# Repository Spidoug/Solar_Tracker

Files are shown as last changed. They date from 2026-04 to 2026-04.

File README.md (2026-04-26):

# Solar Tracker

videoframe_57683

**Solar Tracker** is an Arduino-based photovoltaic panel positioning system. It uses two LDR sensors, an irradiance input, a servo motor, a compass module, an RTC module, EEPROM persistence, and a browser-based Web Serial control interface to keep a solar panel aligned with the most favorable light direction during the configured operating window.

The project combines embedded control and a lightweight web dashboard. The Arduino firmware performs the real-time tracking logic, while the HTML interface allows the operator to connect through USB serial, set angles, sync the RTC, configure sunrise and sunset times, adjust magnetic declination, toggle operation modes, record calibration data, and export CSV files.



## Project objective

The objective of this project is to maximize solar energy capture by orienting a photovoltaic panel toward the best available solar incidence angle throughout the day. The system is designed for small photovoltaic installations, educational experiments, solar-energy research, and prototypes that need low-cost automatic solar tracking.

The tracker uses LDR readings to compare light intensity on the east and west sides of the panel, an analog irradiance input to estimate solar incidence, an HMC5883L compass module to support orientation checks, and an RTC module to keep operation limited to a configured sunrise-to-sunset period. Configuration values are stored in EEPROM, allowing the system to keep important parameters after power cycling.

## Main features

- Arduino firmware for UNO, NANO, MEGA, and compatible boards.
- Servo-based panel angle control from **30° to 150°**.
- Active solar tracking based on LDR difference and PID control.
- Passive solar tracking based on time progression between sunrise and sunset.
- Manual positioning mode through the serial menu or web interface.
- Auto-calibration routine for finding the angle with maximum irradiance.
- RTC-based operating schedule.
- HMC5883L compass orientation check with magnetic declination compensation.
- EEPROM persistence for operating mode, schedule, magnetic declination, and filter state.
- Sudden-variation filter for reducing unstable movement caused by temporary shadows or fast irradiance disturbances.
- Buzzer alerts for startup, movement, confirmation, orientation errors, RTC errors, compass errors, and invalid input.
- Browser-based control panel using the Web Serial API.
- Real-time chart for irradiance versus panel angle using Chart.js.
- CSV export for calibration or experiment data.
- Included STL files for 3D-printed mechanical parts.

## Repository structure

```text
Solar-Tracker/
├── README.md
├── CHANGELOG.md
├── CONTRIBUTING.md
├── LICENSE
├── NOTICE.md
├── SECURITY.md
├── docs/
│   ├── ARDUINO_FIRMWARE.md
│   ├── HARDWARE_GUIDE.md
│   ├── OPERATING_GUIDE.md
│   ├── SERIAL_PROTOCOL.md
│   ├── WEB_APP.md
│   ├── TROUBLESHOOTING.md
│   └── ORIGINAL_README.md
├── hardware/
│   └── 3d-models/
│       ├── FanStBase.stl
│       ├── FanStGrille.stl
│       ├── FanStVert.stl
│       ├── Laser_Cradle_9mm_SG90.stl
│       ├── Servo_Box_3.stl
│       ├── arduino_uno_bottom.stl
│       └── arduino_uno_top.stl
└── src/
    ├── arduino/
    │   └── Solar_Tracker/
    │       └── Solar_Tracker.ino
    └── web/
        ├── index.html
        └── Solar Tracker.html
```

## System overview

The firmware runs in a loop and reads the sensors once per second. During the configured operating interval, it chooses the appropriate behavior based on the current mode:

In **active mode**, the tracker compares the west and east LDR readings. The difference between these readings becomes the tracking error. The firmware applies a PID-style correction and moves the servo when the error exceeds the configured tolerance.

In **passive mode**, the tracker does not depend primarily on the LDR difference. Instead, it maps the current time between sunrise and sunset to the servo angle range. At sunrise, the servo approaches the minimum angle. At sunset, it approaches the maximum angle.

In **manual mode**, the operator defines the desired angle. The tracker keeps the servo at that manually configured angle until automatic behavior is restored.

Outside the configured operating time, the firmware returns the servo to a neutral position and detaches the servo to reduce unnecessary power consumption.

## Hardware components

The project is designed around commonly available Arduino modules:

| Component | Purpose |
|---|---|
| Arduino UNO/NANO/MEGA or compatible board | Main controller |
| Servo motor, such as SG90 or compatible | Moves the solar panel structure |
| 2 × LDR sensors | Detect light imbalance between east and west sides |
| Irradiance sensor or analog light sensor | Measures solar irradiance through analog input A2 |
| HMC5883L compass module | Provides magnetic orientation data |
| PCF8563 RTC module | Keeps date and time for operating schedule |
| Buzzer | Provides acoustic alerts |
| 3D-printed parts | Mechanical support, servo mount, Arduino case, and structural parts |
| External servo power supply | Recommended for stable motion under load |

## Default pin mapping

| Arduino pin | Connected device | Notes |
|---|---|---|
| A0 | West LDR | Analog input |
| A1 | East LDR | Analog input |
| A2 | Irradiance sensor | Mapped from 0–5 V to 0–1000 W/m² in firmware |
| D3 | Servo signal | PWM-capable output |
| D13 | Buzzer | Tone alerts |
| SDA/SCL | RTC + compass | I2C bus |

For Arduino UNO and NANO, the I2C pins are normally A4/SDA and A5/SCL. For Arduino MEGA, they are normally pins 20/SDA and 21/SCL. Always connect all grounds together, especially when using an external servo power supply.

## Arduino dependencies

Install these libraries in the Arduino IDE before compiling:

- `RTClib`
- `Servo`
- `Adafruit HMC5883 Unified`
- `Adafruit Unified Sensor`, required by the HMC5883 library
- `Wire`, included with the Arduino core
- `EEPROM`, included with the Arduino core

## Getting started

1. Clone or download this repository.
2. Open `src/arduino/Solar_Tracker/Solar_Tracker.ino` in the Arduino IDE.
3. Install the required libraries from the Arduino Library Manager.
4. Select the correct board and serial port.
5. Upload the firmware to the Arduino.
6. Assemble the LDR sensors, irradiance input, compass, RTC, servo motor, and buzzer according to the pin mapping.
7. Open `src/web/index.html` in a browser that supports the Web Serial API.
8. Connect to the Arduino using the **Connect to Arduino** button.
9. Configure time, sunrise/sunset, magnetic declination, and operation mode.
10. Test the servo movement without a heavy panel before installing the final mechanical load.

## Web control interface

The web app is a single HTML file that communicates with the Arduino through USB serial. It provides modules for serial connection, manual angle setting, automatic mode restoration, RTC synchronization, schedule configuration, magnetic declination, active/passive mode switching, sudden-variation filter control, data recording, CSV export, compass display, and an irradiance-versus-angle chart.

The interface sends the same menu commands expected by the Arduino serial menu. For example, the manual angle command sends option `7`, followed by the desired angle.

## Serial menu commands

The firmware exposes a simple text-based serial menu at **9600 baud**:

| Option | Action | Expected follow-up input |
|---|---|---|
| `1` | Adjust system date and time | `YYYY MM DD HH MM SS` |
| `2` | Adjust sunrise time | `HH MM` |
| `3` | Adjust sunset time | `HH MM` |
| `4` | Toggle sudden variation filter | None |
| `5` | Adjust magnetic declination | Decimal value in degrees |
| `6` | Toggle active/passive operation mode | None |
| `7` | Enter manual positioning mode | Angle from 30 to 150; invalid value returns to automatic mode |

The web app uses these commands internally, so both the browser interface and the Arduino Serial Monitor can control the same firmware.

## Operation modes

### Active mode

Active mode uses the two LDR sensors as the main feedback source. The panel moves when the west/east light difference exceeds the tolerance threshold. A PID-style correction is applied using the configured constants in the firmware:

```cpp
float Kp = 0.5, Ki = 0.1, Kd = 0.05;
```

### Passive mode

Passive mode uses the configured sunrise and sunset times to calculate a time ratio. The firmware maps the current time to the servo range from 30° to 150°. This mode is useful when LDR readings are noisy, the sky is partially cloudy, or the mechanical structure requires predictable movement.

### Manual mode

Manual mode allows the operator to set a fixed angle. This is useful for testing, calibration, inspection, or experiments that require a known panel position.

### Auto-calibration

When active operation is enabled, the firmware can scan the servo range, measure irradiance at each angle, and store the best angle found during that scan. This routine helps identify the angle with the highest measured solar incidence at calibration time.

## Data recording and CSV export

The web interface can record values received from the Arduino and export them as a semicolon-separated CSV file named `Solar_Tracker.csv`. The exported columns are:

```text
Date/Time;Angle (°);Irradiance (W/m²);Compass (°)
```

This is useful for testing panel performance, validating the calibration routine, and comparing irradiance values at different angles.

## 3D models

The repository includes STL files for mechanical prototyping:

| File | Description |
|---|---|
| `FanStBase.stl` | Base structure |
| `FanStGrille.stl` | Grille/support element |
| `FanStVert.stl` | Vertical support structure |
| `Laser_Cradle_9mm_SG90.stl` | SG90 servo cradle / small actuator support |
| `Servo_Box_3.stl` | Servo box |
| `arduino_uno_bottom.stl` | Bottom half of Arduino UNO enclosure |
| `arduino_uno_top.stl` | Top half of Arduino UNO enclosure |

Review part dimensions, orientation, infill, and material selection according to the final panel weight and operating environment.

## Recommended workflow

Start with the electronics on a bench before installing the complete mechanical system. Confirm that the RTC is recognized, the compass is working, LDR values change correctly, the irradiance input is within the expected 0–5 V range, and the servo can move across the allowed range without obstruction. After the bench test, assemble the mechanical structure, set the local magnetic declination, align the panel axis, and perform calibration under real sunlight.

## Safety notes

Do not power the servo motor directly from the Arduino 5 V pin when moving a real panel or a heavy mechanism. Use an external regulated supply suitable for the servo current and connect the grounds together. Avoid mechanical end-stop collisions by testing the 30° and 150° limits before attaching the final load.

## Potential expansions

- Add meteorological sensors to account for cloudy or unstable conditions.
- Replace the servo with a stepper motor and lead screw for larger photovoltaic panels.
- Add current, voltage, and power monitoring for real energy-yield evaluation.
- Add SD-card logging for offline data collection.
- Add Wi-Fi, Ethernet, MQTT, or Modbus communication for remote monitoring.
- Add a more complete calibration routine for compass hard-iron and soft-iron correction.
- Add enclosure protection for outdoor operation.

## Documentation

More detailed documentation is available in the `docs/` folder:

- [`docs/HARDWARE_GUIDE.md`](docs/HARDWARE_GUIDE.md)
- [`docs/ARDUINO_FIRMWARE.md`](docs/ARDUINO_FIRMWARE.md)
- [`docs/WEB_APP.md`](docs/WEB_APP.md)
- [`docs/SERIAL_PROTOCOL.md`](docs/SERIAL_PROTOCOL.md)
- [`docs/OPERATING_GUIDE.md`](docs/OPERATING_GUIDE.md)
- [`docs/TROUBLESHOOTING.md`](docs/TROUBLESHOOTING.md)

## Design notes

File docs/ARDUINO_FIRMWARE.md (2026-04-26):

# Arduino Firmware Documentation

Firmware location:

```text
src/arduino/Solar_Tracker/Solar_Tracker.ino
```

The folder name matches the sketch name so it can be opened directly in the Arduino IDE.

## Purpose

The firmware controls the solar tracker by reading light sensors, calculating the best panel position, moving a servo motor, checking compass orientation, managing an RTC schedule, and storing configuration values in EEPROM.

## Libraries

The sketch includes:

```cpp
#include <Wire.h>
#include "RTClib.h"
#include <Servo.h>
#include <Adafruit_HMC5883_U.h>
#include <EEPROM.h>
#include <math.h>
```

Required Arduino libraries: `RTClib`, `Servo`, `Adafruit HMC5883 Unified`, `Adafruit Unified Sensor`, `Wire`, and `EEPROM`.

## Important constants

```cpp
const int westLdr = A0;
const int eastLdr = A1;
const int servoPin = 3;
const int buzzerPin = 13;
const int minLimit = 30, maxLimit = 150;
int servoAngle = 90;
```

The default servo range is limited to 30° through 150° to reduce the risk of mechanical overload or end-stop collision.

## PID-style active tracking

Active mode uses the LDR difference as the control error:

```cpp
int error = westLdrRead - eastLdrRead;
float adjustment = Kp * error + Ki * errorSum + Kd * derivative;
servoAngle = servoAngle + adjustment;
```

Default values:

```cpp
float Kp = 0.5, Ki = 0.1, Kd = 0.05;
```

The integral sum is constrained to avoid excessive accumulated correction.

## Moving average

The firmware applies a moving average to the two LDR inputs using five samples. This helps reduce noise before calculating the tracking error.

## Sudden variation filter

The sudden-variation filter changes the tolerance used to decide whether the servo should move. A higher tolerance makes the tracker less sensitive to sudden or temporary light changes.

## Passive tracking

In passive mode, the firmware calculates how far the current time is between sunrise and sunset, then maps that progress to the servo angle range.

## Manual mode

Manual mode is entered through menu option `7`. If the received angle is between 30° and 150°, the firmware writes that angle to the servo and keeps the tracker in manual mode. If an invalid value is entered, the firmware exits manual behavior and returns to automatic operation.

## EEPROM persistence

The firmware uses a signature byte to determine whether EEPROM has already been initialized:

```cpp
#define EEPROM_SIGNATURE 0xAB
```

Stored values include the filter state, sunrise time, sunset time, operation mode, and magnetic declination.

## Compass heading

The firmware reads the HMC5883L compass module, compensates the heading with magnetic declination and a mechanical offset, and normalizes the result to 0°–360°.

## Auto-calibration

The auto-calibration routine scans the full servo range from 30° to 150°. For each angle, it reads the irradiance input and tracks the angle with the highest measured value. After the scan, the servo moves to the best angle found.

## Firmware review note

When preparing this project for hardware testing, review the initialization order of the RTC and compass modules in `setup()`. The current sketch starts compass calibration before the compass initialization block appears later in `setup()`. If the compass does not respond correctly, move the compass initialization step before the calibration routine.

## Suggested firmware improvements

Add structured serial messages, a menu option for manually starting auto-calibration, safer servo ramping, EEPROM versioning, configurable PID constants, and validation for schedule values.

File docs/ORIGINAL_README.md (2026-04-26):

# Solar Tracker

Solar tracker

This code implements a solar tracker system using an Arduino, which controls a servo motor to adjust the angle of a solar panel based on readings from two LDRs and an irradiance sensor. Additionally, there is a compass module (HMC5883) to correct the system's orientation and an RTC module (real-time clock) to manage the operating time (from sunrise to sunset).

The central logic includes active and passive operation modes, PID control to adjust the servo motor, and auto-calibration functionality to identify the best solar exposure angle. The EEPROM is used to store important settings such as schedules, magnetic declination, sudden variation filter state, and the operating mode.

379955969-d62eb5dc-f63b-43ab-a22d-1e1633ed56ea

1. Project Objective

The solar tracking system is designed to maximize solar energy capture by orienting a photovoltaic panel at the optimal angle throughout the day. Utilizing LDR sensors, a compass module, a servo motor, an RTC (Real-Time Clock), and EEPROM for parameter storage, the system ensures precise alignment to the sun and adapts to lighting conditions, providing precise and automated control with a calibration mechanism and manual adjustments.

2. General Structure and Operation

The system is structured with a set of functions and variables to manage and monitor the components of the solar tracker. Below are the main modules and operational flows of the code:

Initialization: Loads configuration data from the EEPROM, sets up the RTC and compass module, and starts the servo motor in a neutral position.
Servo Motor Control: Based on readings from LDR sensors (located to the east and west), the system calculates the error between readings to adjust the panel angle towards the most intense light source.
Calibration and Auto-Adjustment: An auto-calibration function seeks the angle of maximum irradiance, while the compass orientation ensures north-south alignment of the panel.
Operating Modes: Includes active and passive solar tracking modes, as well as a manual mode for independent angle setting.
Storage and Retrieval: The EEPROM saves magnetic declination settings, operation times, and filter status to ensure configuration persistence.

3. Key Components and Functions

RTC (Real-Time Clock): Used to determine sunrise and sunset times, activating the system only during solar incidence periods.
Compass (HMC5883L): Provides magnetic orientation, allowing the panel to precisely align on the north-south axis.
Servo Motor: Responsible for adjusting the solar panel to the optimal light angle, with limits set to avoid overload.
EEPROM: Enables the persistence of configurable parameters, such as magnetic declination, filter status, and operation times.
LDR Sensors: Aid in detecting the direction with the highest solar incidence, orienting the panel based on the light difference between sensors.

4. Positive Points and Relevant Aspects

Dynamic Calibration: The auto-calibration function adjusts the angle automatically based on irradiance, keeping the panel in the ideal position.
Time and EEPROM Configurations: By saving data in the EEPROM, the system preserves settings even after being powered off, eliminating the need for manual reconfiguration.
Error Detection and Sound Alerts: The system includes sound alerts for different situations, such as misalignment and orientation errors, improving interactivity and monitoring.
Flexible Operating Modes: The ability to operate in active, passive, and manual modes adds flexibility and allows adaptation to different usage scenarios.

5. Applications and Potential Expansions

This project can be used in various solar energy applications requiring cost-effective and high-efficiency solar tracking. Some of the main applications include:

Small photovoltaic installations for energy capture in homes or farms.
Self-sustaining energy systems, such as charging stations for electronic devices in remote areas.
Solar efficiency studies in universities and research centers to optimize solar energy use.
Potential Expansions:

Integration with meteorological sensors for adjustment in cloudy conditions.
Implementation of a stepper motor with lead screws, replacing the servo for more efficient movement in larger panels.

6. Conclusion

The code demonstrates a robust implementation of a solar tracking system, offering flexible configurations, persistent storage, and good precision control. With some improvements, particularly in movement logic and module communication, the system could achieve even more efficient and reliable performance, ensuring optimal panel alignment and maximizing solar energy capture.
//////////////////////////////////////////////////////////////////////////////////////////////////////////////////////////////////////////////////////////////////////////////////////////////////

App

The HTML code implements a control interface for the solar tracking system, allowing interaction with an Arduino through the Web Serial API (used to connect the browser to the device). Here are some important details:

Interface Components:
Serial Connection: Allows connecting and disconnecting the Arduino via USB, displaying the connection status.

Angle Adjustment: Enables manual input of an angle between 30° and 150° for the solar panel, with a button to activate automatic mode.

Time and Date Synchronization: Syncs the Arduino's date and time with the local computer.

Sunrise and Sunset Times: Allows adjusting these times that define the operation period of the tracker.

Magnetic Declination: Allows entering and sending the magnetic declination value, essential for correct compass orientation.

Tracking Mode and Sudden Variation Filter: Switches between active/passive modes of tracker operation and enables/disables the filter that smooths sudden irradiance variations.

Data Recording: Starts and stops data recording for auto-calibration (angle, irradiance, compass) and allows exporting the data as CSV.

Compass Display: Shows the current compass value in real-time.

Irradiance Chart: A bar chart correlating the solar panel angle with the measured irradiance.

Data Reading and Sending Functionality:
The interface reads data from the Arduino via serial communication and processes values such as angle, irradiance, and compass orientation.
The bar chart is updated in real-time, showing the relationship between the panel angle and irradiance.
Collected data can be exported in CSV format for further analysis.
API Used:
Web Serial API: Allows communication between the browser and serial devices (such as Arduino), essential for sending commands and receiving data without needing to reload the page.

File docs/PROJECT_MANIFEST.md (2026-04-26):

# Project Manifest

Generated GitHub-ready project structure.

## Included source files

- `src/arduino/Solar_Tracker/Solar_Tracker.ino`
- `src/web/index.html`

## Included STL files

- `FanStBase.stl` (4,266,773 bytes)
- `FanStGrille.stl` (692,484 bytes)
- `FanStVert.stl` (2,490,036 bytes)
- `Laser_Cradle_9mm_SG90.stl` (137,084 bytes)
- `Servo_Box_3.stl` (65,584 bytes)
- `arduino_uno_bottom.stl` (327,084 bytes)
- `arduino_uno_top.stl` (222,584 bytes)

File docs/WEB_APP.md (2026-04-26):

# Web App Documentation

Web app location:

```text
src/web/index.html
```

The web interface is a single-page HTML application for controlling and monitoring the Arduino solar tracker through USB serial communication.

## Main technologies

- HTML, CSS, and JavaScript.
- Web Serial API for browser-to-Arduino communication.
- Chart.js for the irradiance chart.

The page imports Chart.js from a CDN. An internet connection may be required unless Chart.js is downloaded and referenced locally.

## Browser requirements

Use a browser with Web Serial API support, commonly Chromium-based browsers such as Chrome or Edge. The page must run in a context allowed by the browser for serial access.

## Interface modules

The interface includes serial connection controls, angle adjustment, RTC synchronization, sunrise/sunset settings, magnetic declination, active/passive mode switching, sudden-variation filter control, data recording, compass display, alerts, and an irradiance chart.

## Data parsing

The web app searches received serial text using regular expressions:

```js
const angleMatch = data.match(/Angle:\s*(\d+)/);
const irradianceMatch = data.match(/Irradiance:\s*([\d.]+)/);
const compassMatch = data.match(/Orientation:\s*([\d.]+)/);
```

For best results, keep the Arduino serial output format compatible with those labels.

## CSV output

The CSV export uses semicolons:

```text
Date/Time;Angle (°);Irradiance (W/m²);Compass (°)
```

## Possible improvements

Bundle Chart.js locally for offline operation, add a raw serial log window, add configuration import/export, improve Web Serial error messages, and add structured command acknowledgements from the Arduino.

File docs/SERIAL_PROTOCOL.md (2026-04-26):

# Serial Protocol

The Solar Tracker firmware communicates over USB serial at:

```text
9600 baud
```

The protocol is menu-based. The operator sends a numeric option followed by additional values when required.

## Command summary

| Command | Action | Follow-up input | Example |
|---|---|---|---|
| `1` | Set RTC date and time | `YYYY MM DD HH MM SS` | `1\n2026 4 26 14 30 0\n` |
| `2` | Set sunrise time | `HH MM` | `2\n06 00\n` |
| `3` | Set sunset time | `HH MM` | `3\n18 00\n` |
| `4` | Toggle sudden variation filter | None | `4\n` |
| `5` | Set magnetic declination | Decimal degrees | `5\n-22.75\n` |
| `6` | Toggle active/passive mode | None | `6\n` |
| `7` | Manual positioning | Angle 30–150 | `7\n90\n` |
| `7` + invalid angle | Return to automatic behavior | Out-of-range value | `7\n999\n` |

## Status output

The firmware prints status messages containing date, time, angle, west LDR reading, east LDR reading, irradiance, and compass orientation. The web app extracts angle, irradiance, and orientation values from these messages.

## Design recommendation

For future versions, consider adding a machine-readable output format such as:

```text
DATA;angle=90;irradiance=620.5;compass=32.4;west=512;east=500
```

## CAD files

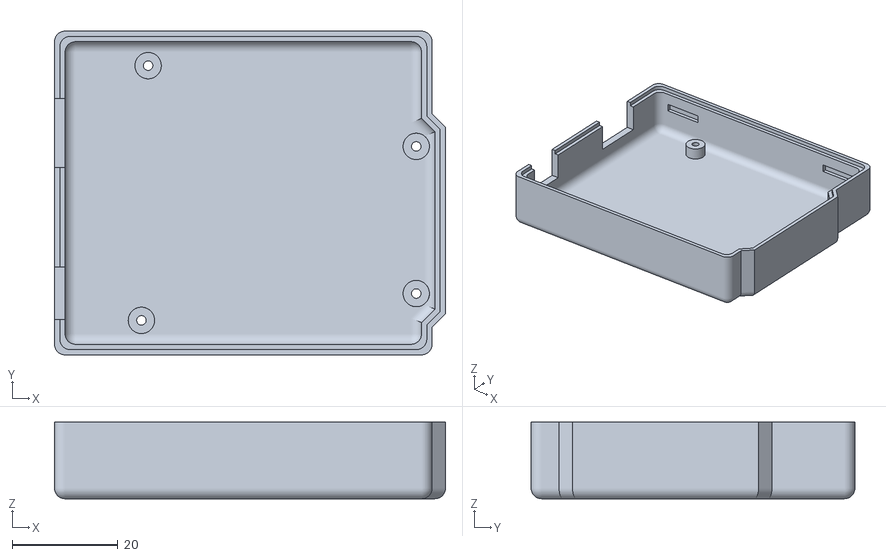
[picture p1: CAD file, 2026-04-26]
hardware/3d-models/arduino_uno_bottom.stl
74.1 x 61.3 x 14.5

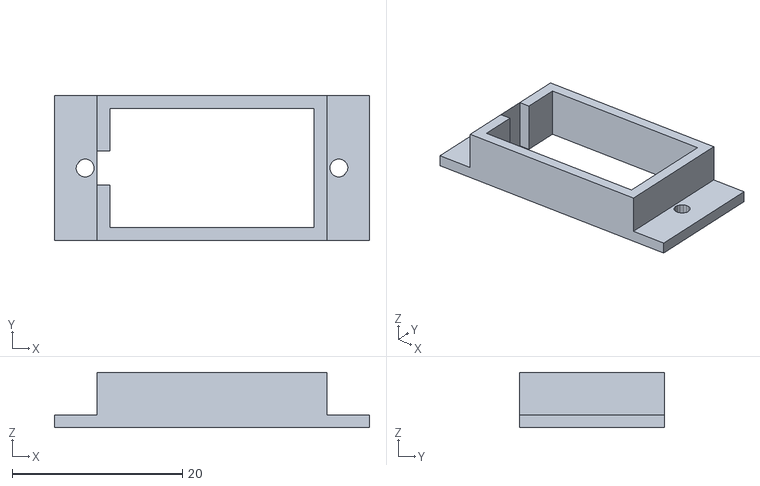
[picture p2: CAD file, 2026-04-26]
hardware/3d-models/Servo_Box_3.stl
37.0 x 17.0 x 6.50

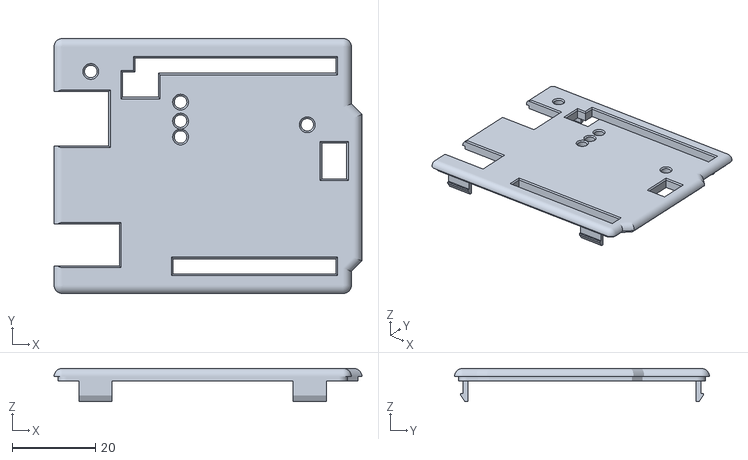
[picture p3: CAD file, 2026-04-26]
hardware/3d-models/arduino_uno_top.stl
74.1 x 61.3 x 8.00

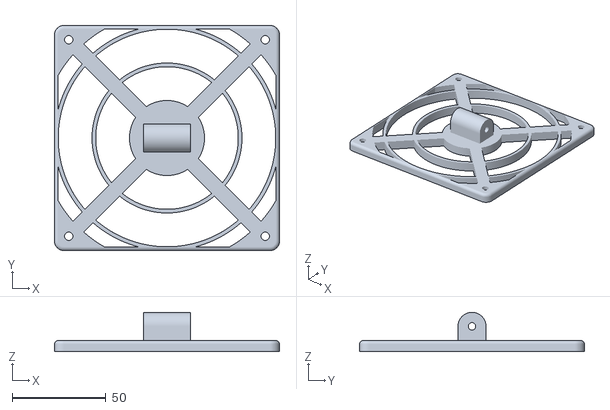
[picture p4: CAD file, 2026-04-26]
hardware/3d-models/FanStGrille.stl
120.0 x 120.0 x 21.0

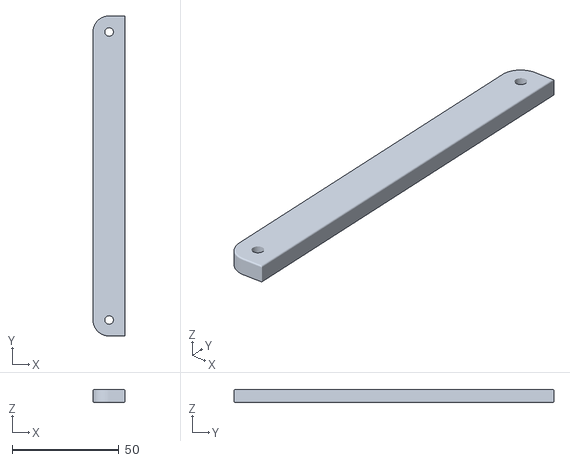
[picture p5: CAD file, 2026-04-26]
hardware/3d-models/FanStVert.stl
15.0 x 150.0 x 6.00

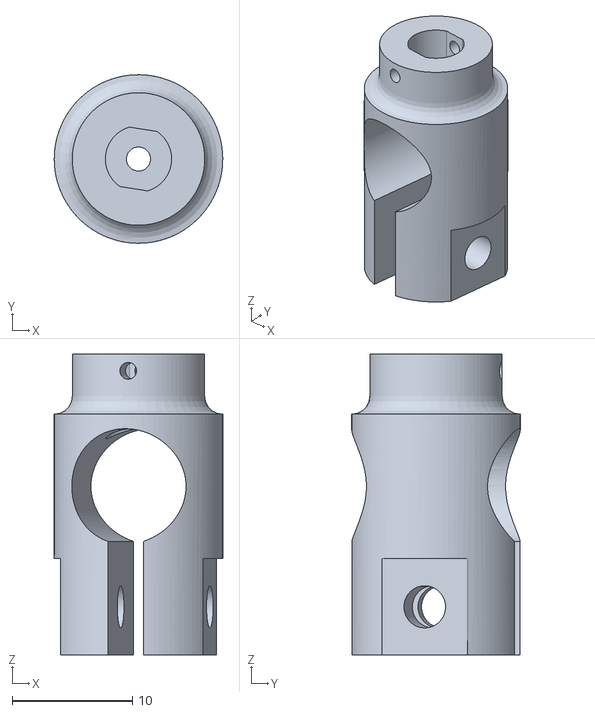
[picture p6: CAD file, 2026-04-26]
hardware/3d-models/Laser_Cradle_9mm_SG90.stl
14.0 x 14.0 x 25.0

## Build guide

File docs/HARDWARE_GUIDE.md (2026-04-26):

# Hardware Guide

This document describes the physical and electrical structure of the Solar Tracker project.

## Main hardware blocks

The system is divided into six hardware blocks: Arduino controller, light sensing block, irradiance measurement input, servo motor actuation, I2C orientation/time modules, and acoustic buzzer alerts.

## Recommended components

| Component | Recommended type | Function |
|---|---|---|
| Microcontroller | Arduino UNO, NANO, MEGA, or compatible | Runs the firmware |
| Servo motor | SG90 for small prototypes; stronger servo for larger panels | Adjusts panel angle |
| LDR sensors | 2 light dependent resistors with voltage dividers | Detect east/west light imbalance |
| Irradiance input | Analog sensor or calibrated light sensor module | Provides approximate W/m² value |
| Compass | HMC5883L module | Measures magnetic heading |
| RTC | PCF8563 module | Keeps time for sunrise/sunset schedule |
| Buzzer | Passive or active buzzer | Audible state/error feedback |
| Power supply | External regulated servo supply | Prevents Arduino reset during servo movement |

## Pin mapping

| Arduino pin | Signal | Description |
|---|---|---|
| A0 | West LDR | Analog sensor reading from west side |
| A1 | East LDR | Analog sensor reading from east side |
| A2 | Irradiance sensor | Analog input mapped to 0–1000 W/m² |
| D3 | Servo PWM | Servo signal line |
| D13 | Buzzer | Tone output |
| SDA/SCL | I2C bus | RTC and compass communication |

## LDR sensor arrangement

The two LDRs should be installed with a small divider or shade wall between them. The goal is to create a measurable difference when the panel is not perpendicular to the dominant light direction. One sensor should represent the east side, and the other should represent the west side.

The firmware calculates:

```text
error = westLdrRead - eastLdrRead
```

If the error exceeds the configured tolerance, the servo angle is corrected.

## Irradiance input

The firmware reads the irradiance input from `A2` and maps it as follows:

```cpp
int a2Value = analogRead(A2);
float a2Voltage = (a2Value / 1023.0) * 5.0;
float irradiance = (a2Voltage / 5.0) * 1000.0;
```

This means that, by default, 0 V corresponds to 0 W/m² and 5 V corresponds to 1000 W/m². If your sensor has another scale, adjust the formula in the firmware.

## Servo motor wiring

Use an external servo supply when the system moves a real panel or a structure with meaningful mechanical load. The Arduino 5 V pin is not recommended for heavy servo current.

| Servo wire | Connect to |
|---|---|
| Signal | Arduino D3 |
| VCC | External 5 V supply or appropriate servo supply |
| GND | External supply GND and Arduino GND |

## I2C wiring

The RTC and compass share the I2C bus.

| Board | SDA | SCL |
|---|---|---|
| Arduino UNO/NANO | A4 | A5 |
| Arduino MEGA | 20 | 21 |

## Compass installation

The compass should be mounted away from high-current wires, motors, steel screws, magnets, and other magnetic interference sources. Keep the sensor orientation fixed relative to the tracker frame.

## Mechanical files

The `hardware/3d-models/` directory contains STL files for prototyping. Before printing, review scale, orientation, servo compatibility, infill, material behavior outdoors, panel weight, and wind load.

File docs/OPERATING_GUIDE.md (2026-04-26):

# Operating Guide

This guide explains how to operate the Solar Tracker after the hardware has been assembled and the firmware has been uploaded.

## 1. Bench test first

Before mounting a photovoltaic panel, test the system on a bench. Confirm the servo moves safely between 30° and 150°, the LDR values change when shaded, the irradiance input changes with light level, the RTC is detected, the compass is detected, and the buzzer alerts are audible.

## 2. Upload the firmware

Open this file in the Arduino IDE:

```text
src/arduino/Solar_Tracker/Solar_Tracker.ino
```

Install the required libraries, select the correct board and port, then upload.

## 3. Open the web interface

Open:

```text
src/web/index.html
```

Click **Connect to Arduino** and select the correct serial port.

## 4. Synchronize date and time

Use **Sync Time and Date** to set the RTC using the computer time. Passive mode and operating-hour checks depend on RTC values.

## 5. Configure sunrise and sunset

Set the desired operating interval. The default values stored by the firmware are 06:00 and 18:00. Outside this interval, the firmware returns the servo to a neutral angle and detaches it.

## 6. Configure magnetic declination

Set the magnetic declination for the installation location. This helps the compass orientation check produce a more accurate heading.

## 7. Choose operation mode

Use passive mode for predictable time-based movement, active mode for LDR-based tracking, and manual mode for inspection or fixed-angle testing.

## 8. Use the sudden variation filter

Enable the sudden variation filter when shadows, reflections, or clouds cause unstable LDR readings.

## 9. Record experiment data

Use **Start Recording** before a calibration scan or test. The interface stores parsed angle, irradiance, and compass data. Use **Stop Recording and Save CSV** to export the dataset.

## 10. Field installation checklist

Check mechanical freedom, servo limits, external power stability, common ground, RTC time, symmetric LDR installation, compass interference, magnetic declination, cable strain relief, and outdoor protection.

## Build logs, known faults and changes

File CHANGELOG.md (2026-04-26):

# Changelog

## 1.0.0

Initial GitHub-ready structure with Arduino firmware, Web Serial interface, STL hardware models, README, and detailed documentation.

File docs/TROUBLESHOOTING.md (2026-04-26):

# Troubleshooting

## Arduino does not appear in the web app

Confirm the USB cable supports data, the Arduino driver is installed, the Arduino Serial Monitor is closed, the browser supports Web Serial, and the USB cable is reconnected if needed.

## Web Serial connection opens but no data appears

Confirm both firmware and web app use 9600 baud. Press reset on the Arduino after connecting and check whether another program is using the serial port.

## Servo jitters or resets the Arduino

Use an external power supply for the servo, connect grounds together, add decoupling capacitance if needed, and check for mechanical friction or overload.

## Servo moves in the wrong direction

Swap the physical east/west LDR positions or invert the control logic in firmware. Confirm A0 is connected to the west LDR and A1 to the east LDR.

## Tracker keeps moving too often

Enable the sudden variation filter, increase tolerance in firmware, improve the LDR divider, or add stronger averaging/filtering.

## RTC not found

Check SDA/SCL wiring, module power, ground, and I2C pull-ups.

## Compass not found or heading is unstable

Check SDA/SCL wiring, keep the compass away from motors and magnets, review compass initialization order in `setup()`, and recalibrate by rotating the sensor.

## Irradiance data is incorrect

Confirm the sensor output is within 0–5 V and adjust the conversion formula if the sensor scale is not 0–1000 W/m².

## CSV file is empty

Start recording before running the test and confirm the web app is receiving serial lines containing angle, irradiance, and orientation labels.

## 3D parts do not fit

Verify printer scale, units, servo dimensions, and print tolerances. Reinforce parts if the panel or mount is heavier than the prototype design.

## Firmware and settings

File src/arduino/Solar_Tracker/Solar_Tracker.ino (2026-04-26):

#include <Wire.h>
#include "RTClib.h"
#include <Servo.h>
#include <Adafruit_HMC5883_U.h>
#include <EEPROM.h>
#include <math.h>

// Function declarations
void solarAutoCalibration();
void checkOrientation();
bool isTimeWithinRange(DateTime now, int startHour, int startMin, int endHour, int endMin);
void adjustSystemTime();
void adjustSunriseTime();
void adjustSunsetTime();
void adjustMagneticDeclination();
void displayMenu();
void processInput();
void displayCurrentStatus(DateTime now);
void initialSoundAlert();
void compassCalibrationSoundAlert();
void servoMovementSoundAlert();
void confirmationSoundAlert();
void orientationConfirmationSound();
void orientationErrorSoundAlert();
void rtcErrorSoundAlert();
void compassErrorSoundAlert();
void inputErrorSoundAlert();
void saveFilterStateToEEPROM();
void loadFilterStateFromEEPROM();
void saveTimingsToEEPROM();
void loadTimingsFromEEPROM();
void saveMagneticDeclinationToEEPROM();
void loadMagneticDeclinationFromEEPROM();
void loadActiveOperationModeFromEEPROM();
void saveActiveOperationModeToEEPROM();
void checkEEPROM();
float getCompassOrientation();
void resetErrorSum();
void calibrateCompass();
void debounce(int pin, int& previousRead, int& currentRead);
void adjustAutoCalibrationTime();
void manualAdjustment();

// Servo motor
Servo servoMotor;

// Set the min and max axis values for compass calibration
float magX_min = -32768, magX_max = 32767;
float magY_min = -32768, magY_max = 32767;
float magZ_min = -32768, magZ_max = 32767;

// Servo, LDRs and other components
const int westLdr = A0;
const int eastLdr = A1;
const int servoPin = 3;
const int buzzerPin = 13;

// PID control variables and solar system
float Kp = 0.5, Ki = 0.1, Kd = 0.05;
float previousError = 0, errorSum = 0;
const float maxErrorSum = 1000;
float maxIrradiance = 0.0;
int maxIrradianceAngle = 90;
const int minLimit = 30, maxLimit = 150;
int servoAngle = 90;

// RTC and compass
RTC_PCF8563 rtc;
Adafruit_HMC5883_Unified compass = Adafruit_HMC5883_Unified(12345);

// Compass module position compensation
float compVl = 33.01;

// Timing and periodic readings
unsigned long lastReadingTime = 0;
const unsigned long readingInterval = 1000;

// Sunrise and sunset timings (default values)
int sunriseHour = 6;
int sunriseMinute = 0;
int sunsetHour = 18;
int sunsetMinute = 0;

// Magnetic declination
float magneticDeclination = 0.0; // Default value

// Previously undeclared variables
int previousWestLdrRead = 0;
int previousEastLdrRead = 0;
float previousIrradiance = 0.0;
int maxTolerance = 100;

// Sudden variation filter variables
bool suddenVariationFilterEnabled = false;
bool activeOperationMode = false;
bool manualMode = false;
unsigned long lastAlert = 0;
const unsigned long alertInterval = 1000;  // 1-second interval for misalignment beeps

// Serial reading buffer
String inputBuffer = "";

// Alignment control variables
bool correctOrientation = false;
bool misalignmentAlert = false;

// Moving average variables
int westLdrAverage[5] = {0};
int eastLdrAverage[5] = {0};
int averageIndex = 0;
int westLdrSum = 0;
int eastLdrSum = 0;

#define EEPROM_SIGNATURE 0xAB  // EEPROM signature identifier

// EEPROM addresses for each setting
const int EEPROM_ADDR_SIGNATURE = 0;
const int EEPROM_ADDR_FILTER_STATE = 1;
const int EEPROM_ADDR_SUNRISE_HOUR = 2;
const int EEPROM_ADDR_SUNRISE_MINUTE = 3;
const int EEPROM_ADDR_SUNSET_HOUR = 4;
const int EEPROM_ADDR_SUNSET_MINUTE = 5;
const int EEPROM_ADDR_OPERATION_MODE = 6;
const int EEPROM_ADDR_DECLINATION_HIGH = 7;
const int EEPROM_ADDR_DECLINATION_LOW = 8;

void setup() {

  // Play initial sound
  initialSoundAlert();

  // Check if EEPROM data is correct
  checkEEPROM();

  // Load the sudden variation filter state from EEPROM
  loadFilterStateFromEEPROM();

  // Load timings and magnetic declination from EEPROM
  loadTimingsFromEEPROM();

  // Load last system operation mode from EEPROM
  loadActiveOperationModeFromEEPROM();

  // Load Magnetic Declination value from EEPROM
  loadMagneticDeclinationFromEEPROM();

  // Initialize servo motor on designated pin
  servoMotor.attach(servoPin);
  servoMotor.write(servoAngle);

  // Initialize serial communication
  Serial.begin(9600);
  while (!Serial);

  Serial.println(F("Solar Tracker"));
  Serial.println(F(""));

  // Start compass calibration
  calibrateCompass();

  // Display menu at startup
  displayMenu();

  if (suddenVariationFilterEnabled) {
    Serial.println(F(""));
    Serial.println(F("Sudden variation filter enabled."));
    Serial.println(F(""));
  } else {
    Serial.println(F(""));
    Serial.println(F("Sudden variation filter disabled."));
    Serial.println(F(""));
  }

  if (activeOperationMode) {
    Serial.println(F(""));
    Serial.println(F("Operation mode is set to active."));
    Serial.println(F(""));
  } else {
    Serial.println(F(""));
    Serial.println(F("Operation mode is set to passive."));
    Serial.println(F(""));
  }

  // Initialize RTC
  if (!rtc.begin()) {
    rtcErrorSoundAlert();
    Serial.println(F("RTC not found."));
    Serial.println(F(""));
    while (1);
  }
  if (rtc.lostPower()) {
    rtc.adjust(DateTime(F(__DATE__), F(__TIME__)));
  }

  // Initialize HMC5883L compass module
  if (!compass.begin()) {
    compassErrorSoundAlert();
    Serial.println(F("Failed to initialize compass."));
    Serial.println(F(""));
    while (1);
  }
}

void loop() {
  DateTime now = rtc.now();
  checkOrientation();

  // Non-blocking serial input reading
  while (Serial.available()) {
    char c = Serial.read();
    if (c == '\n') {
      processInput();
      inputBuffer = "";
    } else {
      inputBuffer += c;
    }
  }

  if (millis() - lastReadingTime >= readingInterval) {
    // Read LDRs with moving average
    westLdrSum -= westLdrAverage[averageIndex];
    eastLdrSum -= eastLdrAverage[averageIndex];
    westLdrAverage[averageIndex] = analogRead(westLdr);
    eastLdrAverage[averageIndex] = analogRead(eastLdr);
    westLdrSum += westLdrAverage[averageIndex];
    eastLdrSum += eastLdrAverage[averageIndex];
    averageIndex = (averageIndex + 1) % 5;

    int westLdrRead = westLdrSum / 5;
    int eastLdrRead = eastLdrSum / 5;

    // Irradiance calculation
    int a2Value = analogRead(A2);
    float a2Voltage = (a2Value / 1023.0) * 5.0;
    float irradiance = (a2Voltage / 5.0) * 1000.0;

    if (manualMode == true) {
      displayCurrentStatus(now);
    } else {
      if (isTimeWithinRange(now, sunriseHour, sunriseMinute, sunsetHour, sunsetMinute)) {
        if (servoMotor.attached() == false) {
          servoMotor.attach(servoPin);
        }
        if (activeOperationMode == true) {
          // Active mode: control based on LDRs
          int error = westLdrRead - eastLdrRead;

          if (suddenVariationFilterEnabled) {
            maxTolerance = 100;
          } else {
            maxTolerance = 10;
          }

          if (abs(error) > maxTolerance) {  // Adjusted tolerance to 10
            errorSum += error;
            errorSum = constrain(errorSum, -maxErrorSum, maxErrorSum);  // Limit error sum
            float derivative = error - previousError;
            float adjustment = Kp * error + Ki * errorSum + Kd * derivative;
            previousError = error;
            servoAngle = servoAngle + adjustment;
            servoAngle = constrain(servoAngle, minLimit, maxLimit);
            servoMotor.write(servoAngle);
            servoMovementSoundAlert();
          } else {
            resetErrorSum();  // Reset error sum when within tolerance
          }
        } else {
          // Passive mode: move servo proportionally to time within solar interval

          // Calculate the total operating period in minutes
          int startMinutes = sunriseHour * 60 + sunriseMinute;
          int endMinutes = sunsetHour * 60 + sunsetMinute;
          int currentMinutes = now.hour() * 60 + now.minute();
          int totalTime = endMinutes - startMinutes;  // Total operating time in minutes
          int elapsedTime = currentMinutes - startMinutes;  // Time since sunrise

          // Calculate angle based on elapsed time
          float timeRatio = (float)elapsedTime / (float)totalTime;
          servoAngle = minLimit + timeRatio * (maxLimit - minLimit);

          // Constrain angle within limits
          servoAngle = constrain(servoAngle, minLimit, maxLimit);

          // Move servo to calculated angle
          servoMotor.write(servoAngle);
        }
        displayCurrentStatus(now);

      } else {
        servoAngle = 90;  // Neutral position outside operating hours
        servoMotor.write(servoAngle);
        Serial.println(F("Outside operating hours."));
        Serial.println(F(""));
        servoMotor.detach();
      }
    }

    previousWestLdrRead = westLdrRead;
    previousEastLdrRead = eastLdrRead;
    previousIrradiance = irradiance;

    lastReadingTime = millis();
  }
}

// Function to check if EEPROM values are valid and initialize with default values if necessary
void checkEEPROM() {
  // Check if EEPROM signature is present
  if (EEPROM.read(EEPROM_ADDR_SIGNATURE) != EEPROM_SIGNATURE) {
    // EEPROM not properly initialized, set default values
    EEPROM.write(EEPROM_ADDR_SIGNATURE, EEPROM_SIGNATURE);       // Write signature to indicate initialization
    EEPROM.write(EEPROM_ADDR_FILTER_STATE, 1);                   // Sudden variation filter disabled (0)
    EEPROM.write(EEPROM_ADDR_SUNRISE_HOUR, 06);                   // Sunrise time 6:00
    EEPROM.write(EEPROM_ADDR_SUNRISE_MINUTE, 00);
    EEPROM.write(EEPROM_ADDR_SUNSET_HOUR, 18);                   // Sunset time 18:00
    EEPROM.write(EEPROM_ADDR_SUNSET_MINUTE, 00);
    EEPROM.write(EEPROM_ADDR_OPERATION_MODE, 0);                 // Passive operation mode (0)

    // Default magnetic declination in degrees (0.0), scaled to an integer value
    int declinationDefault = 0 * 100;
    EEPROM.write(EEPROM_ADDR_DECLINATION_HIGH, declinationDefault >> 8);
    EEPROM.write(EEPROM_ADDR_DECLINATION_LOW, declinationDefault & 0xFF);
  }
}

void solarAutoCalibration() {
  Serial.println(F("Starting Auto-Calibration..."));
  Serial.println(F(""));

  // Dynamically determine delay time based on irradiance variation
  int delayTime = 500;

  for (int angle = minLimit; angle <= maxLimit; angle++) {
    servoMotor.write(angle);
    delay(delayTime);

    int a2Value = analogRead(A2);
    float a2Voltage = (a2Value / 1023.0) * 5.0;
    float irradiance = (a2Voltage / 5.0) * 1000.0;

    if (irradiance > maxIrradiance) {
      maxIrradiance = irradiance;
      maxIrradianceAngle = angle;
    }

    // Adjust delay time based on irradiance variation
    if (abs(irradiance - maxIrradiance) < 50) {
      delayTime = 300;  // Reduce delay time if variation is small
    } else {
      delayTime = 500;  // Increase delay time for large variations
    }

    Serial.print(F("Angle: "));
    Serial.print(angle);
    Serial.print(F("° - Irradiance: "));
    Serial.print(irradiance);
    Serial.println(F(" W/m²"));
  }

  servoMotor.write(maxIrradianceAngle);
  Serial.println(F(""));
  Serial.println(F("Auto-Calibration Complete!"));
  Serial.println(F(""));
  Serial.print(F("Best Angle: "));
  Serial.print(maxIrradianceAngle);
  Serial.println(F("°"));
  Serial.print(F("Max Irradiance: "));
  Serial.print(maxIrradiance);
  Serial.println(F(" W/m²"));
  Serial.println(F(""));
}

// Function to check if the current time is within the operating interval (sunrise to sunset)
bool isTimeWithinRange(DateTime now, int startHour, int startMin, int endHour, int endMin) {
  int currentMinutes = now.hour() * 60 + now.minute();
  int startMinutes = startHour * 60 + startMin;
  int endMinutes = endHour * 60 + endMin;

  return (currentMinutes >= startMinutes && currentMinutes <= endMinutes);
}

// Function to reset the error sum (used in PID control)
void resetErrorSum() {
  errorSum = 0;
}

// Compass calibration function
void calibrateCompass() {
  Serial.println(F("Calibrating the compass..."));
  Serial.println(F(""));
  Serial.println(F("Rotate the sensor in all directions to collect calibration data."));

  for (int i = 0; i < 1000; i++) {
    sensors_event_t event;
    compass.getEvent(&event);

    // Update the min and max values of the X, Y, Z axes
    magX_min = min(magX_min, event.magnetic.x);
    magX_max = max(magX_max, event.magnetic.x);
    magY_min = min(magY_min, event.magnetic.y);
    magY_max = max(magY_max, event.magnetic.y);
    magZ_min = min(magZ_min, event.magnetic.z);
    magZ_max = max(magZ_max, event.magnetic.z);

    delay(10);  // Wait to allow sensor movement
  }

  Serial.println(F(""));
  Serial.println(F("Calibration complete!"));
  Serial.println(F(""));

  // Play compass calibration completion sound
  compassCalibrationSoundAlert();
}

float getCompassOrientation() {
  sensors_event_t event;
  compass.getEvent(&event);

  // Correct X, Y, Z axis readings based on calibrated values
  float magX = (event.magnetic.x - magX_min) / (magX_max - magX_min) * 2 - 1;
  float magY = (event.magnetic.y - magY_min) / (magY_max - magY_min) * 2 - 1;

  // Calculate corrected heading
  float heading = atan2(magY, magX) * 180 / PI;

  // Adjust for negative values and correct for magnetic declination
  heading += magneticDeclination + compVl;

  if (heading < 0) {
    heading += 360;
  }

  if (heading >= 360) {
    heading -= 360;
  }

  return heading;
}

void checkOrientation() {
  float heading = getCompassOrientation();

  if (heading >= 358 || heading <= 2) {
    if (!correctOrientation) {
      correctOrientation = true;
      misalignmentAlert = false;
      orientationConfirmationSound();
      Serial.println(F("Correct orientation with respect to north."));
      Serial.println(F(""));
    }
  } else {
    if (!misalignmentAlert) {
      correctOrientation = false;
      misalignmentAlert = true;
      lastAlert = millis();
      Serial.print(F("Unexpected orientation: "));
      Serial.print(heading);
      Serial.println(F("° . Adjustment needed."));
      Serial.println(F(""));
      orientationErrorSoundAlert();
    }

    if (millis() - lastAlert >= alertInterval) {
      orientationErrorSoundAlert();
      lastAlert = millis();
    }
  }
}

void displayCurrentStatus(DateTime now) {
  float heading = getCompassOrientation();

  Serial.print(F("Date: "));
  Serial.print(now.day(), DEC);
  Serial.print('/');
  Serial.print(now.month(), DEC);
  Serial.print('/');
  Serial.print(now.year(), DEC);
  Serial.print(F(" Time: "));
  Serial.print(now.hour(), DEC);
  Serial.print(':');
  Serial.print(now.minute(), DEC);
  Serial.print(':');
  Serial.print(now.second(), DEC);

  Serial.print(F(" - Angle: "));
  Serial.print(servoAngle);
  Serial.print(F("° - West LDR Reading: "));
  Serial.print(previousWestLdrRead);
  Serial.print(F(" - East LDR Reading: "));
  Serial.print(previousEastLdrRead);
  Serial.print(F(" - Irradiance: "));
  Serial.print(previousIrradiance);
  Serial.print(F(" W/m² - Compass Orientation: "));
  Serial.print(heading);
  Serial.println(F("°"));
}

void displayMenu() {
  Serial.println(F("\nSelect an option:"));
  Serial.println(F(""));
  Serial.println(F("1. Adjust system time"));
  Serial.println(F("2. Adjust sunrise time"));
  Serial.println(F("3. Adjust sunset time"));
  Serial.println(F("4. Toggle sudden variation filter (Enable/Disable)"));
  Serial.println(F("5. Adjust magnetic declination"));
  Serial.println(F("6. Toggle between active or passive operation mode"));
  Serial.println(F("7. Enter manual positioning mode"));
  Serial.println(F(""));
  Serial.println(F("Enter the option number and press Enter."));
  Serial.println(F(""));
}

void processInput() {
  String input = inputBuffer;
  if (input == "1") {
    adjustSystemTime();
  } else if (input == "2") {
    adjustSunriseTime();
  } else if (input == "3") {
    adjustSunsetTime();
  } else if (input == "4") {
    suddenVariationFilterEnabled = !suddenVariationFilterEnabled;
    saveFilterStateToEEPROM();
    if (suddenVariationFilterEnabled) {
      Serial.println(F(""));
      Serial.println(F("Sudden variation filter enabled."));
      confirmationSoundAlert();
    } else {
      Serial.println(F(""));
      Serial.println(F("Sudden variation filter disabled."));
      confirmationSoundAlert();
    }
    Serial.println(F(""));
  } else if (input == "5") {
    adjustMagneticDeclination();
  } else if (input == "6") {
    activeOperationMode = !activeOperationMode;
    saveActiveOperationModeToEEPROM();
    if (activeOperationMode) {
      Serial.println(F(""));
      Serial.println(F("Operation mode is set to active."));
      confirmationSoundAlert();
      solarAutoCalibration();
    } else {
      Serial.println(F(""));
      Serial.println(F("Operation mode is set to passive."));
      confirmationSoundAlert();
    }
    Serial.println(F(""));
  } else if (input == "7") {
    manualAdjustment();
  } else {
    Serial.println(F(""));
    Serial.println(F("Invalid option. Please select a valid option."));
    Serial.println(F(""));
    inputErrorSoundAlert();
  }

  displayMenu();
}

void adjustSystemTime() {
  Serial.println(F(""));
  Serial.println(F("Enter the new date and time in the format: YYYY MM DD HH MM SS"));
  while (Serial.available() == 0);
  String dateTimeInput = Serial.readStringUntil('\n');
  dateTimeInput.trim();
  int year, month, day, hour, minute, second;
  if (sscanf(dateTimeInput.c_str(), "%d %d %d %d %d %d", &year, &month, &day, &hour, &minute, &second) == 6) {
    rtc.adjust(DateTime(year, month, day, hour, minute, second));
    Serial.println(F("Date and time adjusted!"));
    confirmationSoundAlert();
  } else {
    Serial.println(F("Invalid input. Please follow the format: YYYY MM DD HH MM SS"));
    inputErrorSoundAlert();
  }
  Serial.println(F(""));
}

void adjustSunriseTime() {
  Serial.println(F(""));
  Serial.println(F("Enter the sunrise time in the format: HH MM"));
  while (Serial.available() == 0);
  String sunriseInput = Serial.readStringUntil('\n');
  sunriseInput.trim();
  int sunriseH, sunriseM;
  if (sscanf(sunriseInput.c_str(), "%d %d", &sunriseH, &sunriseM) == 2) {
    sunriseHour = sunriseH;
    sunriseMinute = sunriseM;
    saveTimingsToEEPROM();
    Serial.println(F("Sunrise time adjusted!"));
    confirmationSoundAlert();
  } else {
    Serial.println(F("Invalid input. Please follow the format: HH MM"));
    inputErrorSoundAlert();
  }
  Serial.println(F(""));
}

void adjustSunsetTime() {
  Serial.println(F(""));
  Serial.println(F("Enter the sunset time in the format: HH MM"));
  while (Serial.available() == 0);
  String sunsetInput = Serial.readStringUntil('\n');
  sunsetInput.trim();
  int sunsetH, sunsetM;
  if (sscanf(sunsetInput.c_str(), "%d %d", &sunsetH, &sunsetM) == 2) {
    sunsetHour = sunsetH;
    sunsetMinute = sunsetM;
    saveTimingsToEEPROM();
    Serial.println(F("Sunset time adjusted!"));
    confirmationSoundAlert();
  } else {
    Serial.println(F("Invalid input. Please follow the format: HH MM"));
    inputErrorSoundAlert();
  }
  Serial.println(F(""));
}

void manualAdjustment() {
  Serial.println(F(""));
  Serial.println(F("Enter the solar panel angle between 30° to 150°. If the input is invalid, the system will operate in automatic mode."));
  while (Serial.available() == 0);
  String angleInput = Serial.readStringUntil('\n');
  angleInput.trim();
  int angle = angleInput.toInt();
  if (angle >= 30 & angle <= 150) {
    manualMode = true;
    servoAngle = angle;
    if (servoMotor.attached() == false) {
      servoMotor.attach(servoPin);
    }
    servoMotor.write(servoAngle);
    confirmationSoundAlert();
    Serial.println(F("Angle manually set. The system is now in manual mode!"));
    Serial.println(F(""));
    orientationConfirmationSound();
  } else {
    Serial.println(F("Invalid input. Please enter a valid number."));
    Serial.println(F(""));
    Serial.println(F("The system is now in automatic mode!"));
    Serial.println(F(""));
    inputErrorSoundAlert();
    manualMode = false;
  }
}

void adjustMagneticDeclination() {
  Serial.println(F("Enter the magnetic declination value (in degrees):"));
  while (Serial.available() == 0);
  String declinationInput = Serial.readStringUntil('\n');
  declinationInput.trim();
  float declination = declinationInput.toFloat();
  if (declination != 0 || declinationInput == "0") {
    magneticDeclination = declination;
    saveMagneticDeclinationToEEPROM();
    Serial.println(F("Magnetic declination adjusted!"));
    Serial.println(F(""));
    orientationConfirmationSound();
  } else {
    Serial.println(F("Invalid input. Please enter a valid number."));
    Serial.println(F(""));
    inputErrorSoundAlert();
  }
}

void saveFilterStateToEEPROM() {
  EEPROM.write(1, suddenVariationFilterEnabled);
}

void loadFilterStateFromEEPROM() {
  suddenVariationFilterEnabled = EEPROM.read(1);
}

void saveTimingsToEEPROM() {
  EEPROM.write(2, sunriseHour);
  EEPROM.write(3, sunriseMinute);
  EEPROM.write(4, sunsetHour);
  EEPROM.write(5, sunsetMinute);
}

void loadTimingsFromEEPROM() {
  sunriseHour = EEPROM.read(2);
  sunriseMinute = EEPROM.read(3);
  sunsetHour = EEPROM.read(4);
  sunsetMinute = EEPROM.read(5);
}

void saveActiveOperationModeToEEPROM() {
  EEPROM.write(6, activeOperationMode);
}

void loadActiveOperationModeFromEEPROM() {
  activeOperationMode = EEPROM.read(6);
}

void saveMagneticDeclinationToEEPROM() {
  int declinationInt = magneticDeclination * 100;
  EEPROM.write(7, declinationInt >> 8);
  EEPROM.write(8, declinationInt & 0xFF);
}

void loadMagneticDeclinationFromEEPROM() {
  int declinationInt = (EEPROM.read(7) << 8) | EEPROM.read(8);
  magneticDeclination = declinationInt / 100.0;
}

void initialSoundAlert() {
  tone(buzzerPin, 1000, 200);
  delay(300);
  noTone(buzzerPin);
}

void compassCalibrationSoundAlert() {
  tone(buzzerPin, 8000, 500);
  delay(900);
  noTone(buzzerPin);
}
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
